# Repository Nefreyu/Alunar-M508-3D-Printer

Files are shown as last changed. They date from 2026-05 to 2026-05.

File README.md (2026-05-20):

# ALUNAR M508 3D Printer — Instructions & Resources (v2.0)

Official instructions, firmware, software and test files for the **ALUNAR M508** (Prusa i3-style) 3D printer. Version 2.0, released September 2016.

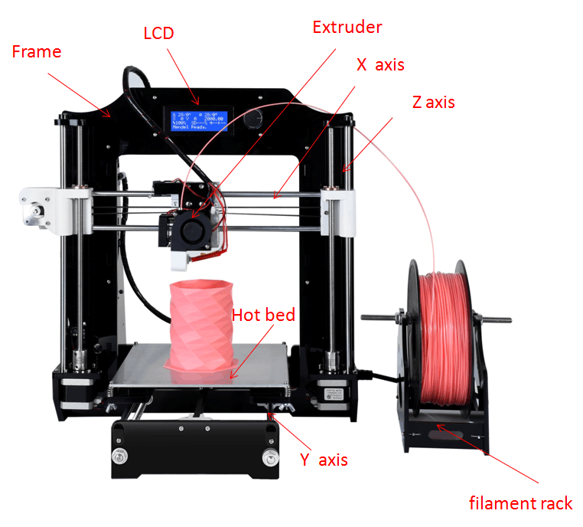
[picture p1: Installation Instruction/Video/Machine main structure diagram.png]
Machine structure


---

## Table of Contents

- [Repository Structure](#repository-structure)
- [Installation Instruction](#installation-instruction)
- [Firmware](#firmware)
- [Software](#software)
- [Test Files](#test-files)
- [Common Problems](#common-problems)
- [Packing List](#packing-list)

---

## Repository Structure

```
├── Installation Instruction/
│   ├── ALUNAR M508 Quick Start Guide_(V2.0).pdf
│   └── Video/
│       ├── 1-Frame assembly.mp4
│       ├── 2-Y-Axis And Hot bed Assembly.mp4
│       ├── 3-Z-X-Axis Assembly.mp4
│       ├── 4-Extruder Assembly.mp4
│       ├── 5-LCD-Assembly.mp4
│       ├── 6-Power And Main board Assembly.mp4
│       ├── 7-Filament Rack Assembly.mp4
│       ├── Open Carton.mp4
│       ├── Power On Inspection.mp4
│       ├── Hot Bed Leveling.mp4
│       ├── LCD Feature And Printing From SD Card.mp4
│       ├── Change Filament When Printing.mp4
│       ├── Manually Change Filament.mp4
│       ├── Test Print.mp4
│       └── finish picture/
├── Firmware/
│   ├── Main_I3/          ← Marlin firmware source code
│   ├── arduino-1.5.4.rar ← Arduino IDE required to flash
│   └── How to download the firmware.pdf
├── Software/
│   ├── RepetierHost_1_0_6/
│   └── Slicing software/
├── TestFile/
│   ├── STLMode/          ← 3D models (.stl)
│   └── TestMode/         ← Ready-to-print G-code files
├── Common problem/
└── Packing list/
```

---

## Installation Instruction

The [`Installation Instruction/`](Installation%20Instruction/) folder contains the full quick start guide and a complete set of assembly videos.

### Quick Start Guide

[ALUNAR M508 Quick Start Guide (V2.0).pdf](Installation%20Instruction/ALUNAR%20M508%20Quick%20Start%20Guide_%28V2.0%29.pdf)

### Assembly Videos

Follow the videos in order for a complete build:

| Step | Video |
|---|---|
| 1 | [Open Carton](Installation%20Instruction/Video/Open%20Carton.mp4) |
| 2 | [Frame Assembly](Installation%20Instruction/Video/1-Frame%20assembly.mp4) |
| 3 | [Y-Axis & Hot Bed Assembly](Installation%20Instruction/Video/2-Y-Axis%20And%20Hot%20bed%20Assembly.mp4) |
| 4 | [Z & X Axis Assembly](Installation%20Instruction/Video/3-Z-X-Axis%20Assembly.mp4) |
| 5 | [Extruder Assembly](Installation%20Instruction/Video/4-Extruder%20Assembly.mp4) |
| 6 | [LCD Assembly](Installation%20Instruction/Video/5-LCD-Assembly.mp4) |
| 7 | [Power & Main Board Assembly](Installation%20Instruction/Video/6-Power%20And%20Main%20board%20Assembly.mp4) |
| 8 | [Filament Rack Assembly](Installation%20Instruction/Video/7-Filament%20Rack%20Assembly.mp4) |

### Operation Videos

| Topic | Video |
|---|---|
| Power On Inspection | [Power On Inspection.mp4](Installation%20Instruction/Video/Power%20On%20Inspection.mp4) |
| Hot Bed Leveling | [Hot Bed Leveling.mp4](Installation%20Instruction/Video/Hot%20Bed%20Leveling.mp4) |
| LCD Features & SD Card Printing | [LCD Feature And Printing From SD Card.mp4](Installation%20Instruction/Video/LCD%20Feature%20And%20Printing%20From%20SD%20Card.mp4) |
| Change Filament While Printing | [Change Filament When Printing.mp4](Installation%20Instruction/Video/Change%20Filament%20When%20Printing.mp4) |
| Manual Filament Change | [Manually Change Filament.mp4](Installation%20Instruction/Video/Manually%20Change%20Filament.mp4) |
| Test Print | [Test Print.mp4](Installation%20Instruction/Video/Test%20Print.mp4) |

> **Note:** Large video files are stored with Git LFS. Make sure you have `git-lfs` installed before cloning: `sudo apt-get install git-lfs && git lfs install`.

---

## Firmware

The [`Firmware/`](Firmware/) folder contains the Marlin-based firmware source for the M508.

- **Source code:** [`Firmware/Main_I3/`](Firmware/Main_I3/) — Arduino sketch (`.ino`) and all associated `.cpp`/`.h` files.
- **Arduino IDE:** [`Firmware/arduino-1.5.4.rar`](Firmware/arduino-1.5.4.rar) — Required version to compile and flash.
- **Flashing guide:** [`Firmware/How to download the firmware.pdf`](Firmware/How%20to%20download%20the%20firmware.pdf)

### Key firmware files

| File | Description |
|---|---|
| `Main_I3/Main_I3.ino` | Main sketch entry point |
| `Main_I3/Configuration.h` | Primary machine configuration (steps/mm, temperatures, etc.) |
| `Main_I3/Configuration_adv.h` | Advanced configuration options |
| `Main_I3/Marlin_main.cpp` | Core Marlin logic |
| `Main_I3/temperature.cpp/h` | Temperature control (hotend & bed) |
| `Main_I3/stepper.cpp/h` | Stepper motor driver |
| `Main_I3/planner.cpp/h` | Motion planning |
| `Main_I3/motion_control.cpp/h` | Arc/straight-line motion |
| `Main_I3/ultralcd.cpp/h` | LCD menu system |
| `Main_I3/cardreader.cpp/h` | SD card support |

### Flashing the firmware

1. Extract `arduino-1.5.4.rar` and install Arduino IDE 1.5.4.
2. Open `Firmware/Main_I3/Main_I3.ino`.
3. Select board: **Arduino Mega 2560**.
4. Connect the printer via USB and upload.

Refer to [`How to download the firmware.pdf`](Firmware/How%20to%20download%20the%20firmware.pdf) for detailed steps with screenshots.

---

## Software

The [`Software/`](Software/) folder contains the tools needed to control the printer and prepare print files.

### Repetier-Host v1.0.6

[`Software/RepetierHost_1_0_6/`](Software/RepetierHost_1_0_6/) — Host software for sending G-code to the printer over USB.

Download from: http://www.repetier.com/

**Setup:**
1. Install the USB serial driver before connecting the printer.
2. Open Repetier-Host and set the correct COM port and baud rate (see [`Baud rate setting.jpg`](Software/RepetierHost_1_0_6/Baud%20rate%20setting.jpg)).
3. Adjust print range settings as shown in [`Print range settings.jpg`](Software/RepetierHost_1_0_6/Print%20range%20settings.jpg).

### Slicing Software — Cura 15.04

[`Software/Slicing software/`](Software/Slicing%20software/) — Converts `.stl` models into `.gcode` files ready to print.

- **Guide:** [`How to use Cura 15.04.pdf`](Software/Slicing%20software/How%20to%20use%20Cura%2015.04.pdf)
- **M508 PLA profile:** [`M508－PLA.ini`](Software/Slicing%20software/M508%EF%BC%8DPLA.ini) — Import this profile in Cura for optimised M508 PLA settings.

---

## Test Files

The [`TestFile/`](TestFile/) folder contains sample models and pre-sliced G-code files to verify the printer is working correctly.

### Ready-to-print G-code (`TestFile/TestMode/`)

| File | Preview |
|---|---|
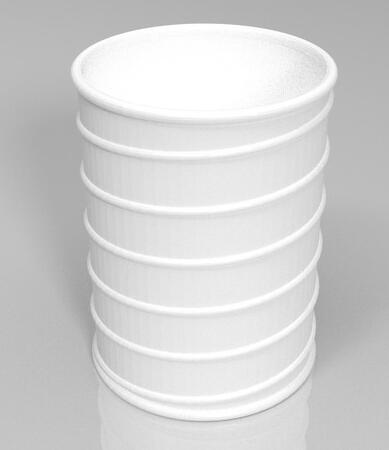
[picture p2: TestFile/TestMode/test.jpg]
test
| `test.gcode` |  |
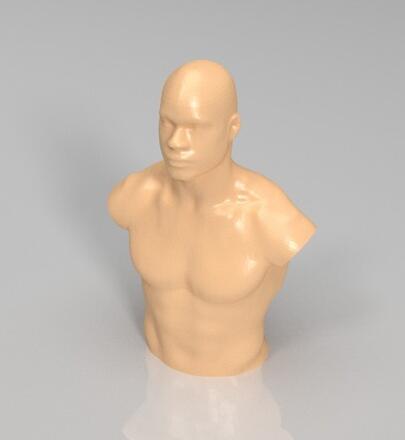
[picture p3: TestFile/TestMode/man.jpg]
man
| `man.gcode` |  |
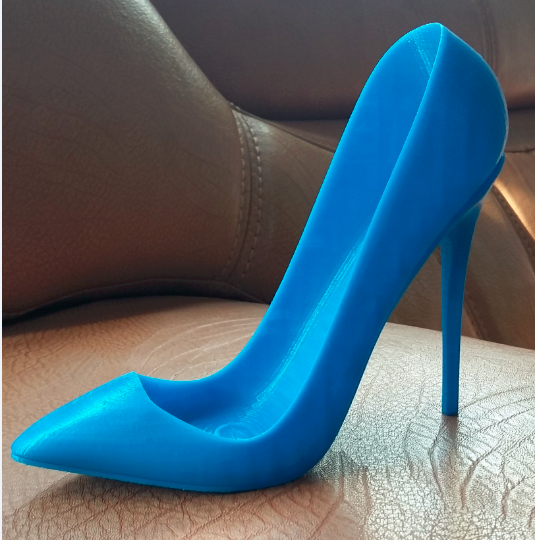
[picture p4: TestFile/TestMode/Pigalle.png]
Pigalle
| `Pigalle.gcode` |  |
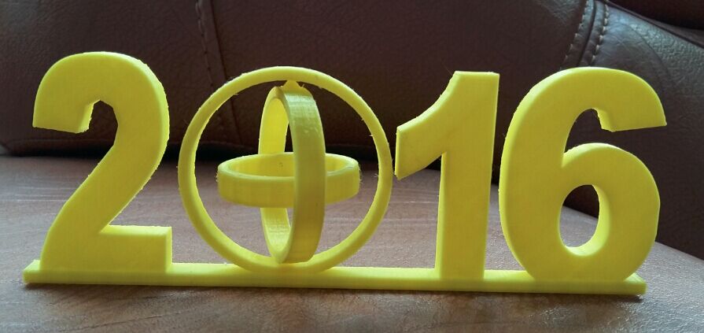
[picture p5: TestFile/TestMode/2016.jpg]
| `2016.gcode` |  |
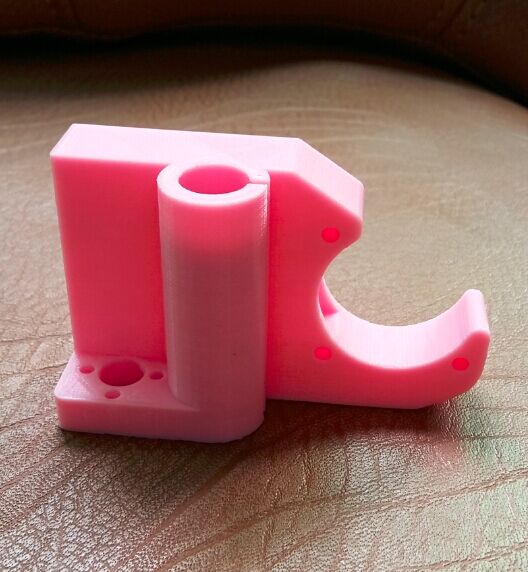
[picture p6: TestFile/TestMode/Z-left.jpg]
Z-left
| `Z-left.gcode` |  |
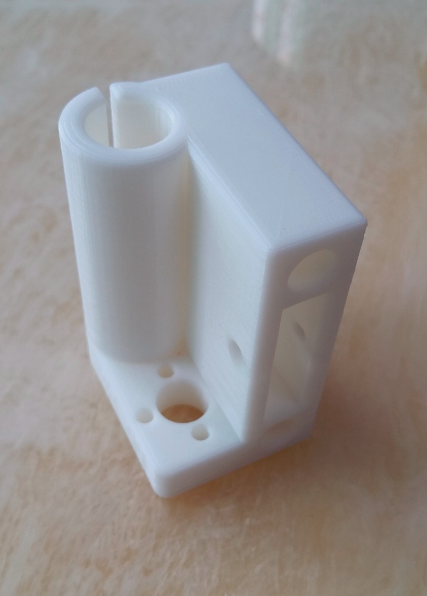
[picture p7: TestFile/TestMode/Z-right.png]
Z-right
| `Z-right.gcode` |  |
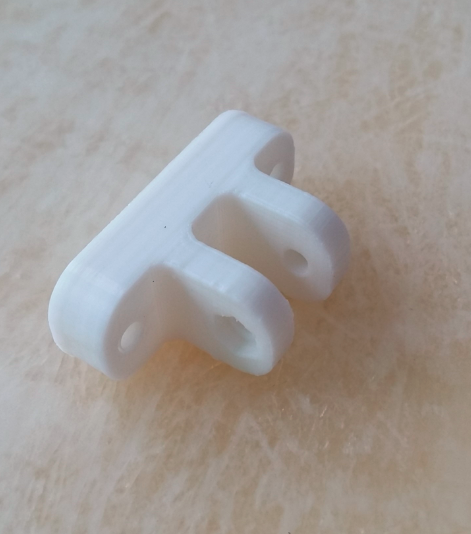
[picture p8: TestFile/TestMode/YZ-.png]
YZ
| `YZ.gcode` |  |
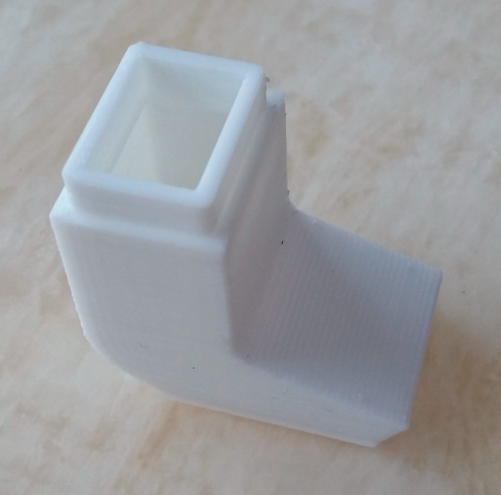
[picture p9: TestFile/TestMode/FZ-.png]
FZ
| `FZ-.gcode` |  |
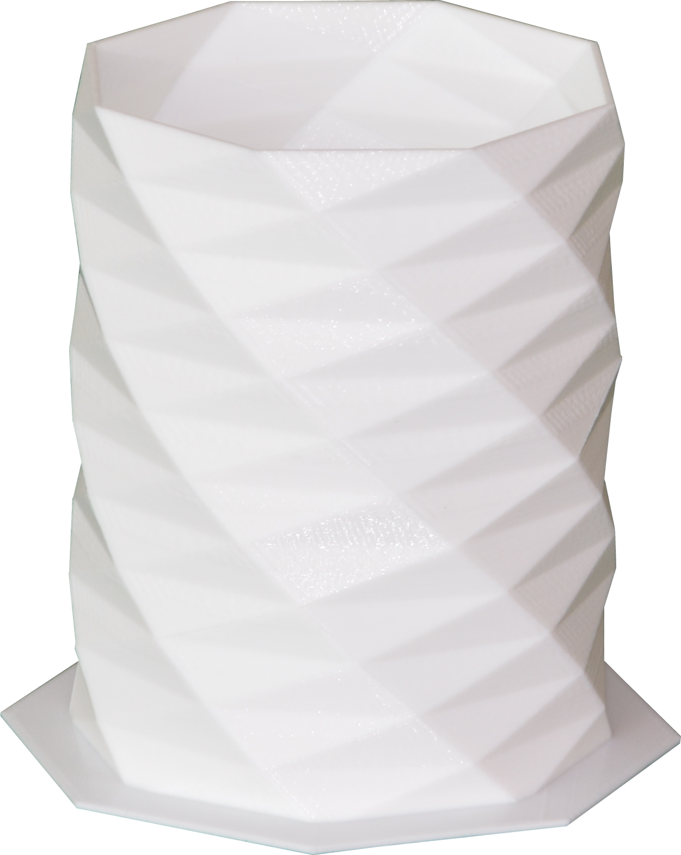
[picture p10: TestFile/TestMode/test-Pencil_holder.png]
Pencil holder
| `test-Pencil_holder.gcode` |  |

### 3D Models (`TestFile/STLMode/`)

| File |
|------|
| `2016.stl` |
| `Pencil_holder.stl` |
| `Pigalle.stl` |
| `FZ-.STL` |
| `YZ.STL` |
| `Z-left.STL` |
| `Z-right.STL` |

---

## Common Problems

The [`Common problem/`](Common%20problem/) folder contains troubleshooting guides:

| Guide | Description |
|---|---|
| [`"Err MINTEMP" Trouble.pdf`](<Common%20problem/%E2%80%9CErr%20%20MINTEMP%20%E2%80%9DTrouble.pdf>) | How to resolve the MINTEMP thermistor error |
| [`LCD Common problem.pdf`](Common%20problem/LCD%20Common%20problem.pdf) | Common LCD display issues and fixes |
| [`Print Quality Troubleshooting Guide.pdf`](Common%20problem/Print%20Quality%20Troubleshooting%20Guide.pdf) | Diagnosing and fixing print quality problems |

---

## Packing List

The [`Packing list/`](Packing%20list/) folder contains the full list of parts included in the M508 kit.

- [`M508 Packing list.pdf`](Packing%20list/M508%20Packing%20list.pdf)
- [`Packing list-M508.pdf`](Packing%20list/Packing%20list-M508.pdf)
- [`Open the carton.jpg`](Packing%20list/Open%20the%20carton.jpg)

---

## Cloning this repository

This repository uses **Git LFS** for large binary files (videos, G-code, STL, RAR). Install Git LFS before cloning:

```bash
sudo apt-get install git-lfs
git lfs install
git clone https://github.com/Nefreyu/Alunar-M508-3D-Printer.git
```

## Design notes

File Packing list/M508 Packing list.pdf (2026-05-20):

No. | Item name No. | Item name Item name | Picture Picture Picture | qty
1 | Frame A | A | 1
2 | Frame B | B | 1
3 | frame unit C | C | 1
4 | frame unit D | D | 1
5 | frame unit H | H | 1
6 | M8 screw rod A length:400mm | | 2
7 | ￠8 Guide rod A length:380mm | 2
8 | linear motion ball slide units | 3
9 | Y axis motor assemble | 1 set
10 | Y bearing support assemble | 1 set

Frame

# Packing list

M3 | PM3*18 | M8

## Y Axis

11 | frame unit P | P | 1
12 | End stop length 1000mm | | 1
13 | frame unit Q | Q | 1
14 | frame unit R | R | 4
15 | frame unit S | S | 2
16 | frame unit L | L | 1
17 | frame unit G | G | 1
18 | Hot bed(with Thermistor) | 1 set
19 | frame unit J | 2

Hot bed

## Z Axis

4-M3*20 | 12-M4*12 | 4-M3*12 | PM3*18 | 2-KA2*12 | M3
4-Spring | 4-M3*30 | 4-M3 | 4-Wing nut M3

J

20 | frame unit K | K | 2
21 | frame unit R | R | 2
22 | frame unit M | M | 2
23 | frame unit N | N | 2
24 | End stop length 400mm | | 1
25 | Z axis motor assemble | | 2 set
26 | ￠8 Guide rod B(length:330mm) | | 2
27 | T8 Threaded rod and nut | | 2 set
28 | Right plastic seat assemble | | 1 set
29 | left plastic seat assemble | | 1set
30 | X axis motor assemble | | 1 set
3-M3*20 | 8-M3*12 | 2-KA2*12 | PM3*18 | M3

## X Axis

31 | ￠8 Guide rod A length:380mm | | 2
32 | U bracket | | 1 set
33 | linear motion ball slide units | | 3
34 | frame unit O | O | 1
35 | End stop length 800mm | | 1
36 | Cooling | 1
37 | Cooling fan | 1
38 | Turbo fan | 1
39 | Fan extender | 1
40 | Extruder motor assemble | 1 set
41 | Nozzle assemble（with thermistor and Cartridge） | 1 set
4-TM4*8 | 2-M4*16 | 2-KA2*12

Extruder

42 | Spare Thermistor | 1
43 | frame unit I | I | 1
44 | Distance washer | | 8
45 | 2004LCD unit | | 1
46 | Knob | | 1
47 | Main control board | 1
48 | Power supply | 1
49 | AC Plug | 1
50 | Power Switch | 1

## LCD

M4*16 | PM3*18
4-PM3*40 | 4-M3 | M3*8

Mainboard、 Mainboard、Power supply Power supply

51 | frame unit E | E | 1
52 | frame unit F | F | 1
53 | Power Supply wire1(red ,yellow,black) | | 3
54 | Power Supply wire2（red) | | 1
55 | Power Supply wire 3 | | 1 set
56 | Motor cables length:600mm | | 3
57 | Motor cables length:1000mm | | 2
58 | power cable | | 1
59 | Tie tube | | 2M
60 | 2GT belt 6mm | | 1.7M
61 | Tie-wrap | | 10
62 | Distance washer | | 3
63 | R clip | 2

64 | M8 screw rod B length:160mm | | 1
65 | frame unit T | T | 2
66 | frame unit U | U | 2
67 | Hexagon screw M3*8 | 6
68 | Hexagon screw M3*12 | 15
69 | Round head screw PM3*18 | 57
70 | Hexagon screw M3*20 | 16
71 | Screw M3*30 | 4
72 | Hexagon screw M3*30 | 4

Filament rack

4-M8 | 4-PM3*18 | M3
3-M3*8 | 3-M3*12 | M3 | PM3*18

Screw,Nut

73 | Round head screw PM3*40 | 6
74 | Screw TM4*8 | 9
75 | Hexagon screw M4*12 | 15
76 | Hexagon screwM4*16 | 5
77 | Screw KA2*12 | 6
78 | Hexago nut M8 | 16
79 | Hexago nut M3 | 67
80 | Wing nut M3 | 6
81 | Washer 8*18*1.5 | 16
82 | Card Reader | 1
83 | Crepe Paper | 1
84 | USB2.0 data cable | 1
85 | SD memory card | 1

Attached parts

86 | Filament | 1
87 | Hexago screw driver 1.5# | 1
88 | Hexago screw driver 2# | 1
89 | Hexago screw driver 2.5# | 1
90 | Hexago screw driver 3# | 1
91 | phillips screw driver 3# | 1
92 | Straight screwdriver 3# | 1
93 | Straight screwdriver 2# | 1
94 | Wrench | 3
95 | Scissor | 1

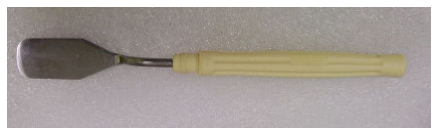
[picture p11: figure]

96 | Trowel | 1
97 | Synchronous belt tension clamp | 2

Tool

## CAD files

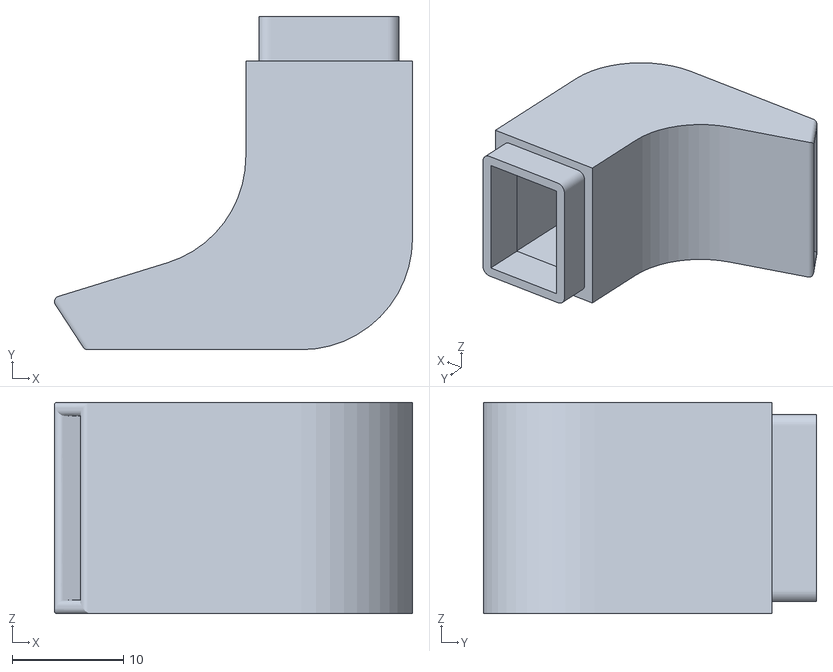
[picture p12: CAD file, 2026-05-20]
TestFile/STLMode/FZ-.STL
32.2 x 30.0 x 19.0

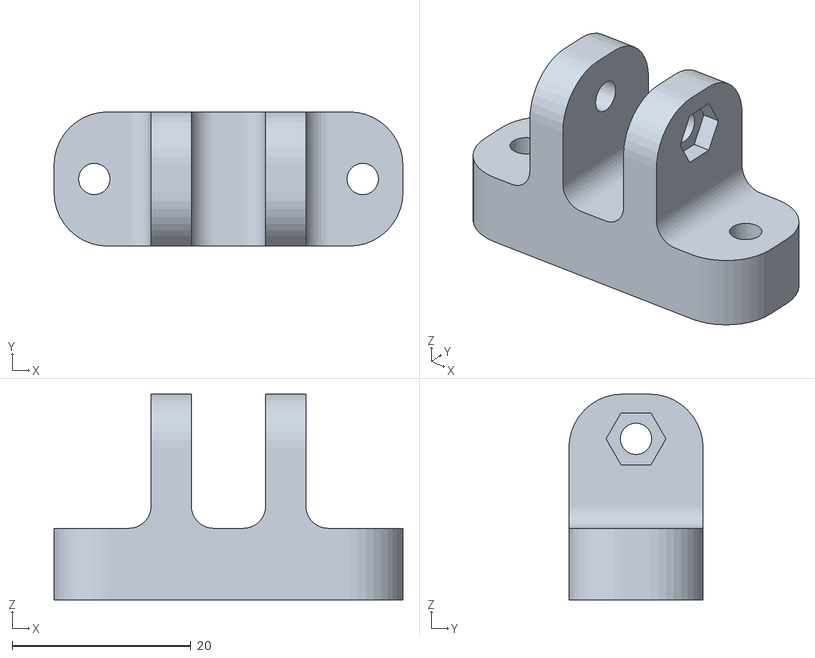
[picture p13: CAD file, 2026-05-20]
TestFile/STLMode/YZ.STL
39.0 x 15.0 x 23.0

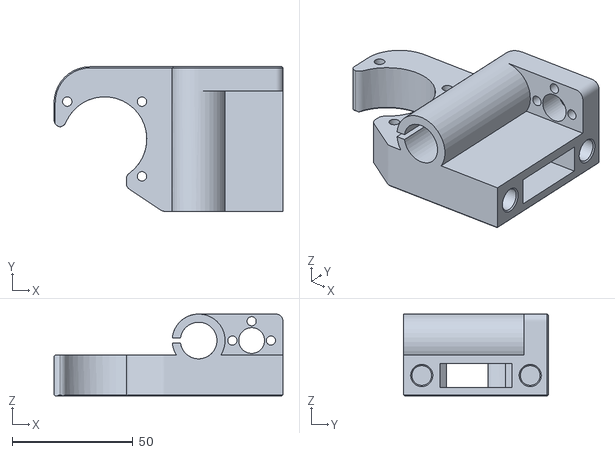
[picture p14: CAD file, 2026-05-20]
TestFile/STLMode/Z-left.STL
95.0 x 60.0 x 34.0

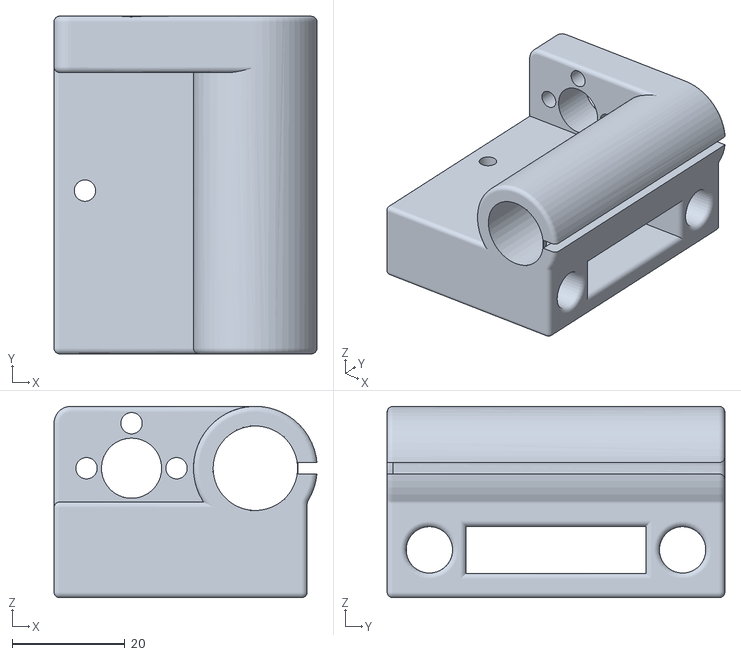
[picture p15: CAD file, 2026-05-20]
TestFile/STLMode/Z-right.STL
46.7 x 60.0 x 34.0

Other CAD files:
TestFile/STLMode/2016.stl
TestFile/STLMode/Pigalle.stl
TestFile/STLMode/Pencil_holder.stl

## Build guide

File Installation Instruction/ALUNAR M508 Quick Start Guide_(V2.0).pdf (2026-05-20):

# ALUNAR 3D Printer M508 Quick Start Guide

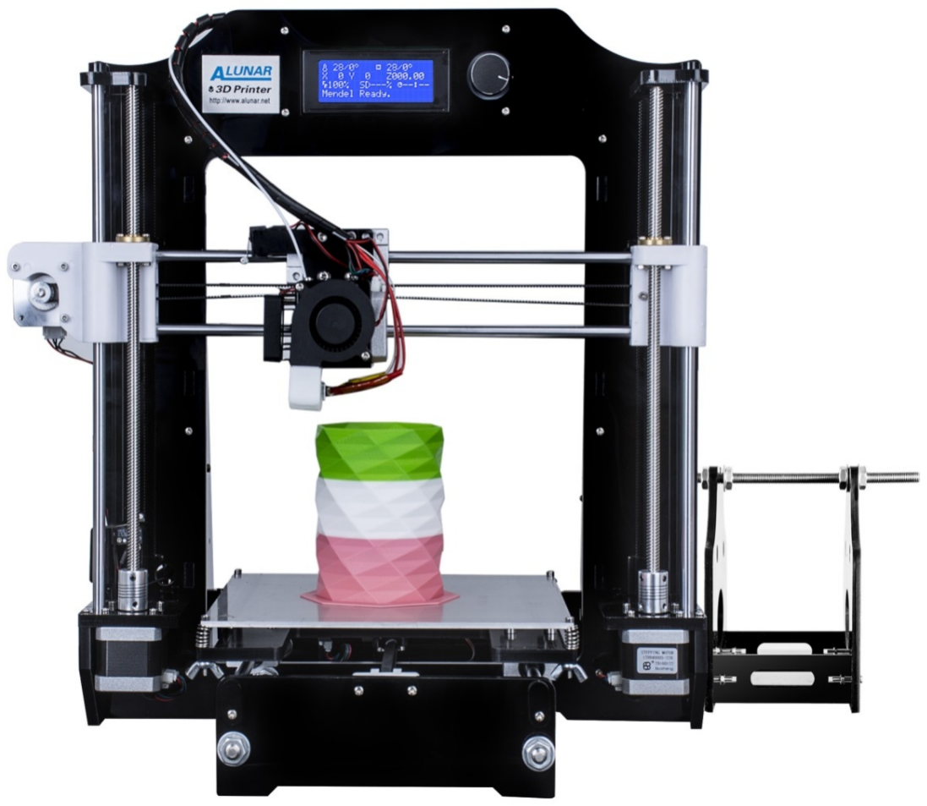
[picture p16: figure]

Service Skype:alunar3d@hotmail.com Service Email:service@alunar.net

# Catalogue

## Foreword

Thanks in advance for choosing our M508 3D Printer! With the Quick Start Guide (hereinafter as “Guide”), you could enjoy accomplishing the assembly, Test and Printing step by step. Meanwhile, you will also learn the structure principle and its special FDM printing technology deeply, and then you will get great progress on not only the theoretical knowledge but also the manipulative ability.
To give play to the bigger effect of the printer and ensure the worry-free buying, smooth and enjoyable using, we spare no effect to consider the problem and difficulty you will meet with from when you order the printer and make detail videos and pictures to show the exact settle way. We write this “Guide” elaborately in great detail and we will always accompany with your using 3D printer. The kits would come to you with high-class parts and need you to put them together. So please read the “Guide” carefully before you assembly and use the printer .Please use the printer in strict accordance with the “Guide” to avoid any defective or invalid use caused by improper operation. So please keep the “Guide” for your easy reference.

Special Tips:

With our objective of constant update for our printer, we would not make future notice to you if some specifications and models updated. And we apologize for the inconvenience would lead to you.
We will do our best to help and solve the problem with our products. Your positive review and feedback are so appreciated!
Wish you a nice day!

## 1. Machine parameters

Printing technology | FDM | Nozzle diameter | 0.3(default),0.4,0.5mm
Print size | 200*200*180mm | Printing precision | 0.1-0.3mm
Filament | PLA /ABS /HIPS/WOOD | Printing speed | 40-100mm/s (proposal)
Filament diameter | ￠1.75mm | Working condition | 10-40℃
Number of extruder | 1 | Humidity | 20-50％

## 2. Flow Diagram for Quick Use Manual

## 3. Important Notice and Attentions

3.1 Keep the assembling operation platform level.
3.2 Please ensure that you move to the right tap position for input voltage (110V or 220V) of the power supply (as shown in the picture).
Calibration | Printing Test | Senior Instruction | Frequently Asked Questions and Settle Way

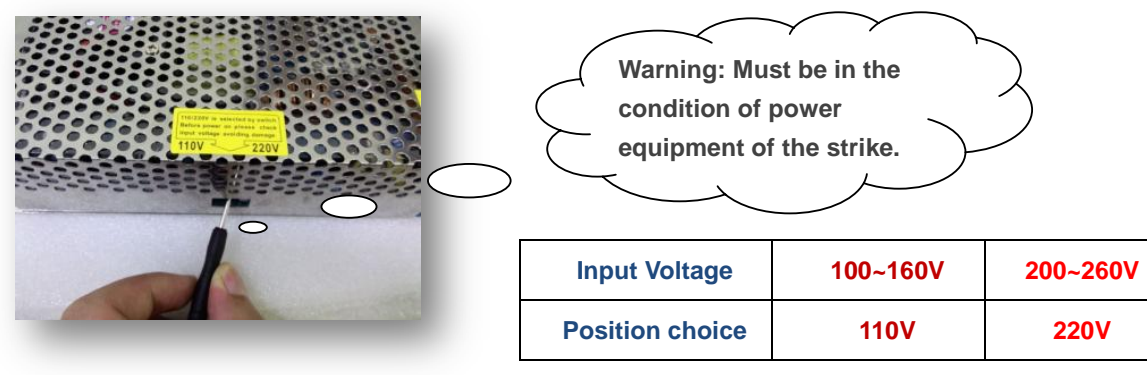
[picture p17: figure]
Input Voltage; Position choice; Warning: Must be in the condition of power equipment of the strike.

3.3 You need to make a proper degree of tightness of the pull belt for X axis& Y axis. 3.4 Ensure manual operation slide smoothly when you install the X, Y, Z axis.
3.5 When equipped the hotbed, you should keep the 4 angle level for sure.
3.6 Ensure the correct wiring for controller board and plug tightly into the exact socket.
3.7 Don’t plug and unplug the wiring for controller board when power on, especially don’t plug and unplug the connect wiring for power supply.
3.8 Don’t touch the extruder and hotbed when printer is power on to avoid the scald.
3.9 Before installation please remove the protective paper.

3.10 Before printing please paste on crepe paper.

## 4. Preparatory Work

1. Tool and kit preparing: one level desk at more than 2 sq. m. size, one computer, one scissor, SD card reader, power supply and so on.
2. Open the box you got, and read the “Guide“ from the SD card. We suggest that you should copy all the documents to the computer from the SD card and then start assembling according to the “Guide” (SD-Card: \Installation Instruction\ALUNAR 3D Printer M508 Quick Start Guide)

## 5. Preinstallation Checklist

### 5.1 Step Way of Opening Box

Please look over the whole box appearance and make sure whether the box is damaged (if damaged, please feel free to contact with our customer service); and then please open the box and check the kits list as per “opening the carton” (SD-Card: \Packing list\Open the carton.)And “Video of opening carton” (SD-Card: \Installation Instruction\Video\ Open Carton.MP4)

### 5.2 Take an account of kits

Please check out all the parts and make sure if any part is lost or damaged as per the “Packing List” (SD-Card: \Packing list) and video “Open carton” (SD-Card: \Installation Instruction\Video\Open Carton.mp4.) Please feel free to contact our customer service once you find out that you lost or got any defective parts (except leading by the inartificial reason). We will try our best to settle your problems as soon as possible）.

## 6. Assembly and Calibration for M508

M508 assembly: Please assembly the printer by following the step1- step7 on assembly diagram and video, and pay attention the prompt for key of assembling.(SD-Card: \Installation Instruction\Video)

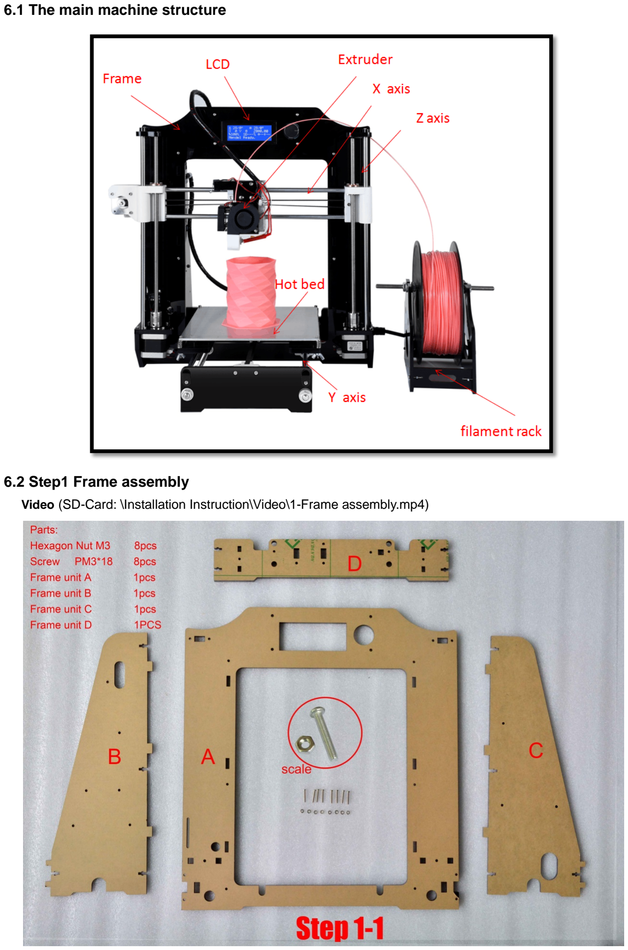
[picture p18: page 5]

### 6.1 The main machine structure

### 6.2 Step1 Frame assembly

Video (SD-Card: \Installation Instruction\Video\1-Frame assembly.mp4)

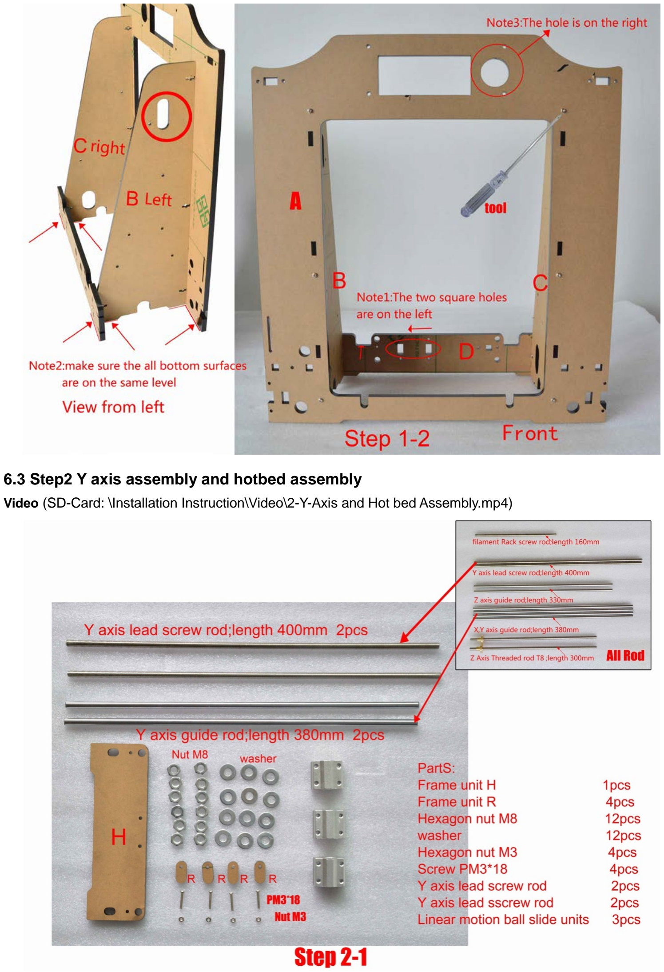
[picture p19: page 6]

### 6.3 Step2 Y axis assembly and hotbed assembly

Video (SD-Card: \Installation Instruction\Video\2-Y-Axis and Hot bed Assembly.mp4)

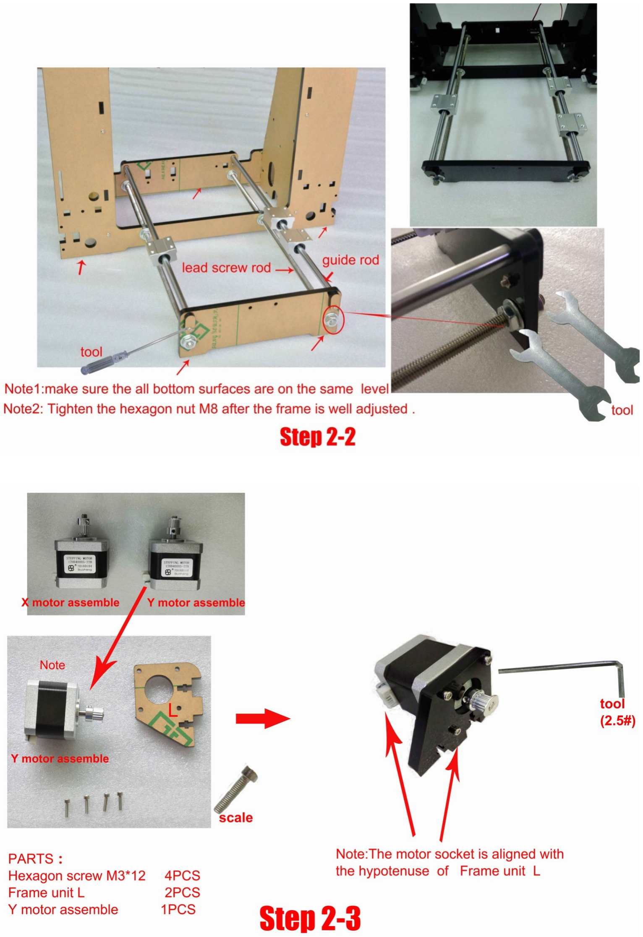
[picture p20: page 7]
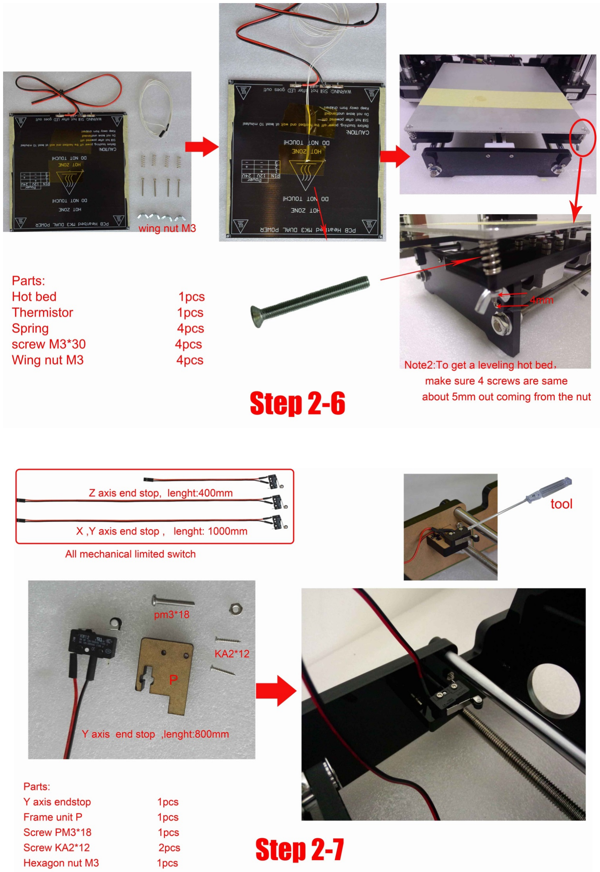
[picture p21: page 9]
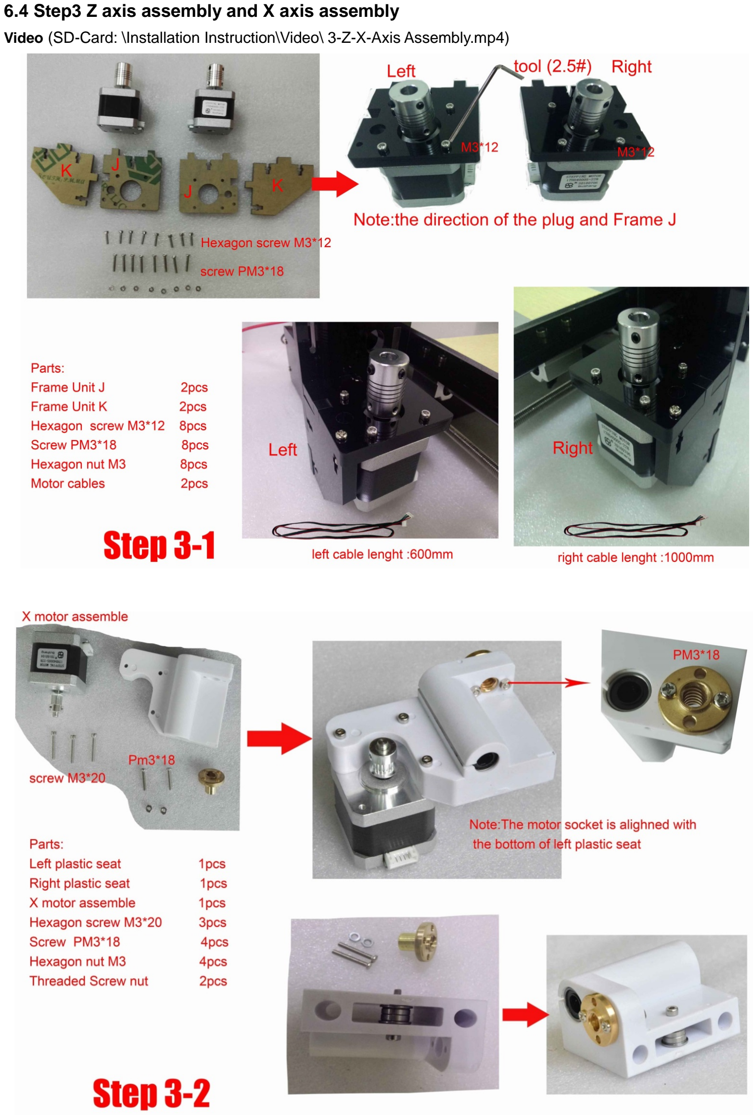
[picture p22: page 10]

### 6.4 Step3 Z axis assembly and X axis assembly

Video (SD-Card: \Installation Instruction\Video\ 3-Z-X-Axis Assembly.mp4)

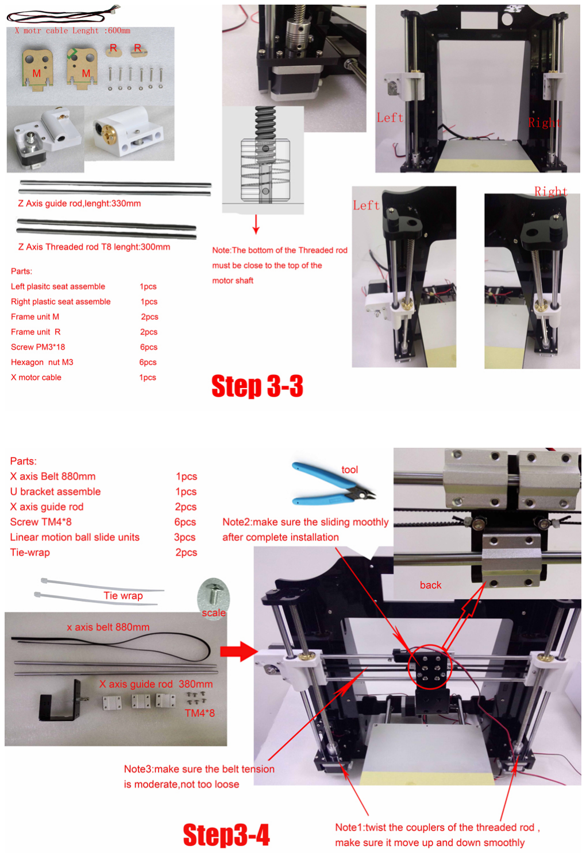
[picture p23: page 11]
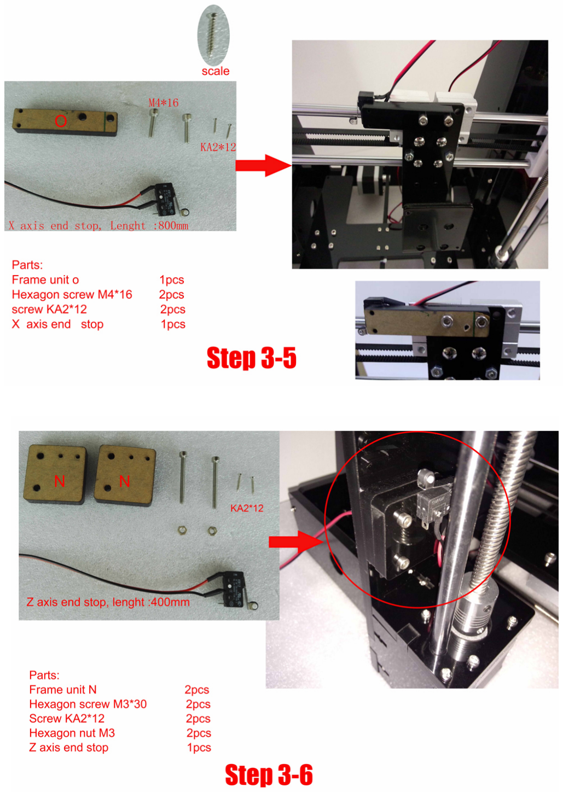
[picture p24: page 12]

### 6.5 Step4 Extruder assembly

Video (SD-Card: \Installation Instruction\Video\ 4-Extruder Assembly.mp4)

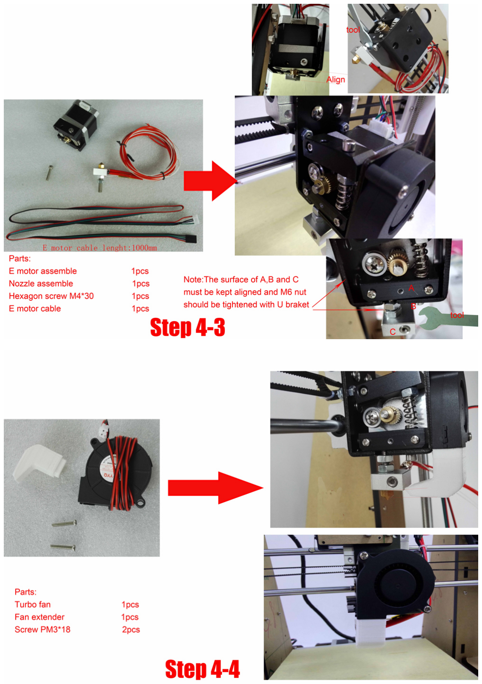
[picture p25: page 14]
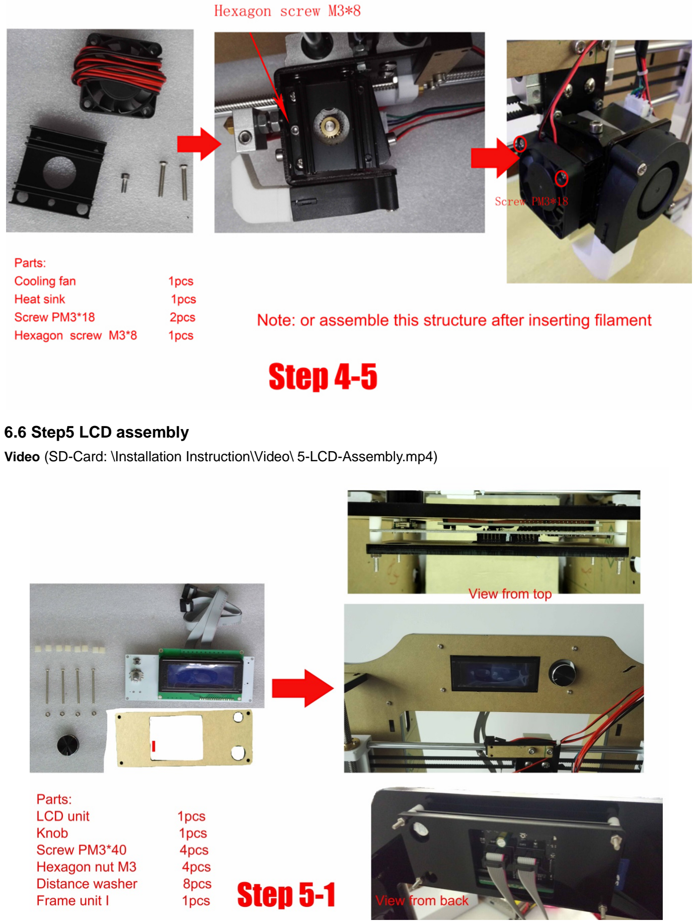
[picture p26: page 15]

### 6.6 Step5 LCD assembly

Video (SD-Card: \Installation Instruction\Video\ 5-LCD-Assembly.mp4)

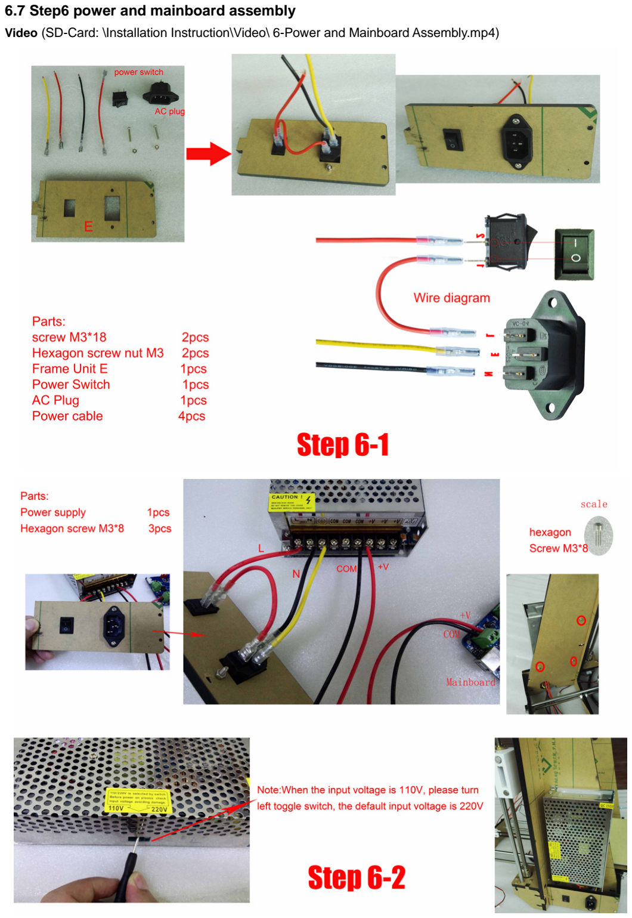
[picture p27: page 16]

### 6.7 Step6 power and mainboard assembly

Video (SD-Card: \Installation Instruction\Video\ 6-Power and Mainboard Assembly.mp4)

### 6.8 Step7 Filament rack assembly

Video (SD-Card: \Installation Instruction\Video\ 7-Filament Rack Assembly.mp4)

## 7. Testing and Commissioning

### 7.1 Power on test

When connecting the power supply to your printer, please make sure whether the power indicator light is on, LCD screen show correctly or not, hotbed and the extruder can be heated rightly or not, the thermistor, turbine fan and radiator fan works normally or not; (SD-Card:\ Installation Instruction\ Video\ Power On Inspection.mp4)

### 7.1.1 Turn on the power switch, LCD display, as shown in Figure

### 7.1.2 Fan check

### 7.1.3 Nozzle and hot bed heating inspection

“Prepare” →“Preheat PLA”

### 7.1.4 Back to the origin inspection

“Prepare” →“Auto Home”

X axis will move towards left, Y axis will move towards back, Z axis will move down, each axis will stop moving till their limit switch

Switch on the power, this fan works

OK | NG | NG

OK

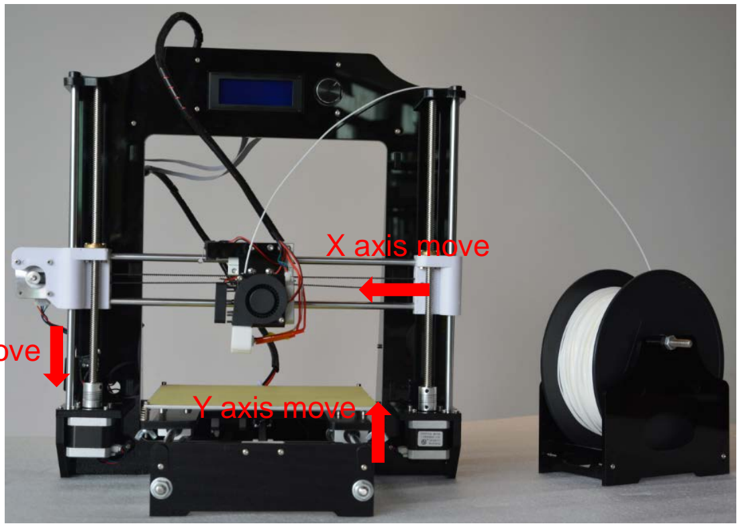
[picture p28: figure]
X axis move; Y axis move

### 7.2 Hotbed leveling test:

Hotbed leveling test: Please make calibration to level the hotbed according to the video(SD-Card:\Installation Instruction\Video\Hot Bed Leveling.mp4)After assembling, you need to level the bed when firstly print

### 7.2.1 Rough Debugging to level hotbed

7.2.1.1 Adjust the screws at the 4 angle of the hotbed to make the screws 4mm out of the nut (Picture 7.1)； 7.2.1.2 Move the nozzle as near as possible to the hotbed, and pull the extruder with hand to the upper everywhere of hotbed to check if the distance between the nozzle and 4 angle of hotbed is accordant(Picture7.2);
7.2.1.3 Hold the T coupling at left& right bottom of Z axis with hand and rotate it to make the nozzle to 4mm above the hotbed (Picture7. 3, 7.4)
7.2.1.4 Move the Z axis limit switch to the proper position, to make that the Z axis stop once the bottom of left Z axis nut support meet the sphere of limit switch (Picture 7.5)

# Z axis move

Picture 7.1 | Picture 7.2 | Picture 7.3

4mm

### 7.2.2 Accurate Debugging

7.2.2.1 Auto home and make the XYZ axis back to origin (Picture 7.6)；
7.2.2.2 Screw the screws at 4 angle of hotbed to make the nozzle above 1mm to the hotbed (Picture 7.7)

(PS: After Auto home, please click “Disable Steppers” or turn off the power, otherwise, you will can’t move the XYZ axis by hand)

### 7.2.3 Fine Debugging when printing

Please check the printing status of first layer when you first printing by your printer. If you need, you can screw the screws at 4 angle of hotbed to the best position (as shown on picture 7.10)
The different printing effect depends on the different distance between nozzle and hotbed：

### 7.3 Change the Filament

Watch the video “Manually Change Filament “and get the operation way of this special feature of this printer (SD-Card: \Installation Instruction\Video\ Manually Change Filament.MP4)

### 7.3.1 Change the Filament when not printing

Pull out the filament: Firstly preheat the nozzle to the exact temperature(PLA：200～220℃，ABS：240～260℃) Once the temperature is up to the same as setting, press the upper aluminum piece on the extruder motor with left hand, meanwhile push down to extrude part of filament and then pull out it rapidly with right hand.(PS:Don't pause in the process to avoid the jam lead by the cooling midway. Picture 7.11, 7.12)
(SD-Card: \Installation Instruction\Video\ Change Filament When Printing.MP4)

Insert the Filament：Press the upper aluminum piece on the extruder motor and meanwhile insert the filament into the throat (You can cut the filament into oblique angle with scissor to plug in smoothly. Picture 7.13), push down to extrude part of filament (Picture7.12), then let the aluminum piece go, finally clear up the filament extruded.

Picture 7.4 | Picture 7.5

Picture 7.6

Picture 7.7

Picture 7.8 | Picture 7.9 | Picture 7.10
The distance between nozzle and hotbed is too high | | The distance between nozzle and hotbed is proper

The nozzle is too close to hotbed

### 7.3.2 Change the Filament When Printing

7.3.2.1 Click “tune” →“change filament”；The printer stop working and the XY axis would be back to the origin, then the extruder would send back the filament from the printer automatically (Picture 7.14)； 7.3.2.2 Change the filament manually and press the knob, then the printer would go on printing starting from the former position of printing model.

### 7.4 Feature Demonstration

Feature Demonstration: watch the video “LCD Feature and Printing from SD Card” and get the operation way of all basic features; (SD-Card: \Installation Instruction\Video\LCD Feature and Printing From SD Card.MP4)

### 7.4.1 Instruction of Operation part for Off-line Printing

Off-line printing operation for 3D printer constitutes 5 parts as below (as shown above Picture 7.16): Power Switch, Outlet, LCD Screen, Spin Button, and SD Card
And you can control the knob easily and quickly by rotating and pressing.

Picture 7.12

Filament

The Upper
Aluminum
Piece
Picture 7.11 | Picture 7.13
Power Switch | Outlet | LCD Screen | Knob | SD Card

Picture7.16

Picture 7.14

Picture 7.15

### 7.4.2 The first Memo Interface

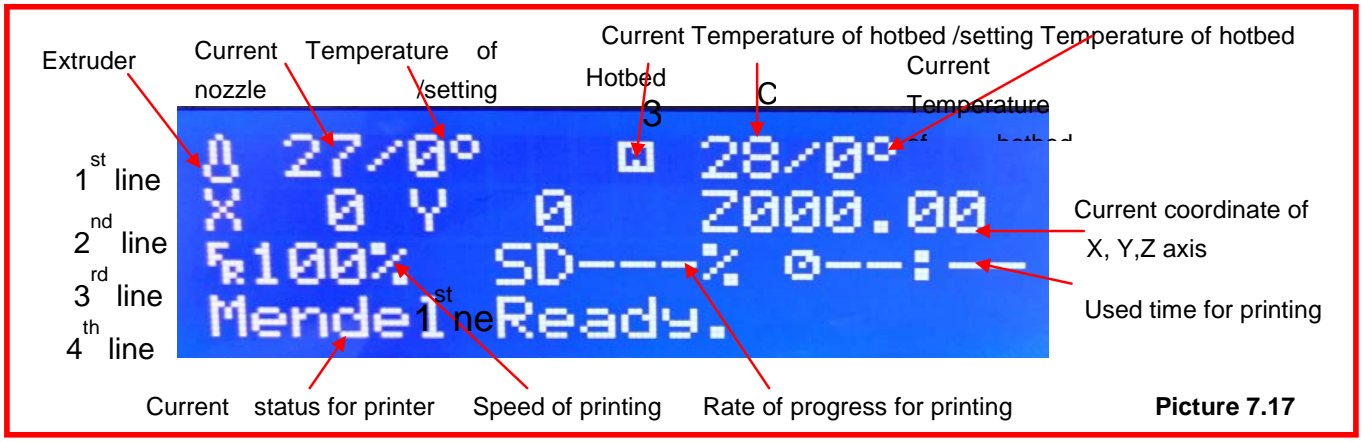
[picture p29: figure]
nozzle; /setting; Temperature of nozzle; Extruder; Hotbed; Current coordinate of X, Y,Z axis; Speed of printing; Rate of progress for printing; Used time for printing; Current Temperature; hotbed; Current status for printer; line; Picture 7.17

Plug the outlet and switch on, then access to the first memo interface (as shown on picture 7.17) which consist of the 4 parts as below:
temperature, XYZ coordinate system, Printing status, Current situation of system
1. 1st line
It will show the temperature of nuzzle and hotbed, the two parts separated by “/” will show respectively before
and after the current and setting temperature, Such as | , it shows that setting
temperature for nuzzle is180°and the current is 72°, it shows that setting temperature for hotbed is 70°and the current is 31°
2. 2nd line
It will show the exact position of XYZ axis move onto in the printing.
3. 3rd line
It will show the speed and rate of progress of printing, and used time for printing. And it shows the multiple speed of printing which is set up in the slicing.“100%” means the exact speed and 200% means that printing by the speed 2 times as the one setting in slicing
4. 4

th
line
It shows the current status of printer, such as

### 7.4.3 The secondary memo interface

Press the knob and access to the 2nd memo interface, and it will show differently as below when the printer is working or not

7.4.3.1 The 2nd memo interface when not printing (as shown on picture 7.18)

Click the (Info screen) and back the 1st page of memo interface
Click the (Prepare) and access to set up for printing prepare such as preheat the nozzle& hotbed, auto home, move the nozzle and hotbed
Click the (Control) and set up for the temperature of nozzle& hotbed, parameter of stepper motor, restoring the fail-safe, and storage memory etc.
Click the (Print from SD) and choose the printing file from the SD card, and it is sort of by copy time.

Current Temperature of hotbed /setting Temperature of hotbed Current Temperature of

Picture7.18

Information
Prepare for printing
Parameter Adjustment
Print from SD

7.4.3.2 The 2nd memo interface when printing (as shown on picture 7.19)

Click the (Info screen) and back the 1st page of memo interface
Click the (Tune) and adjust the temperature of nozzle& hotbed, speed of fan when printing
Click the (Control) and set up for the temperature of nozzle& hotbed, parameter of stepper motor, restoring the fail-safe, and storage memory etc.
Click the (Pause Print) and pause the printing
Rotate down the knob and click the (Stop Print) to stop printing

### 7.4.4 Prepare for printing (prepare)

7.4.4.1 When 3D printer not printing, rotate the knob and click “prepare” in the secondary memo interface (Picture 7.20) and then access to the 3rd memo interface (Picture 7.21)

(1) Unlock the disable stepper motor: click the (Disable Steppers) and then you can manual move the XYZ axis smoothly
(2) Click the (Auto Home) and the XYZ axis will move back to the origin
(3) Click the (Preheat PLA) and then the nozzle would be heating up to the same as the setting temperature for PLA, meanwhile, the LCD will also go back to the first memo interface.
(4) Click the (Preheat ABS) and then the nozzle would be heating up to the same as the setting temperature for ABS, meanwhile, the LCD will also go back to the first memo interface
(5) Click the (Cool down), the temperature for nozzle and hotbed would be cool down to 0°automatically.
(6) Click the (switch power off) to turn off the power (it is not put into use at present)
(7) Click the (Move Axis) to control the move of XYZ, input & output the filament. Please don’t take the 10mm as unit for Z axis movement and input& output the filament (extruder).

### 7.4.5 Move the axis and input& output the filament (Move Axis)

Click the “Move Axis” and do as the guide to all parts, then you will access to the 4th(Picture 7.23), 5th(Picture 7.24), and 6th(Picture 7.25) memo interface step by step. And then you could only take the 1mm & 0.1mm as unit for the Z axis movement and input & output filament (extruder).

Picture 7.19

Information
Current Parameter Adjustment Parameter Adjustment
Pause print
Stop print

Picture 7.21

Picture 7.20

PS: The axis movement is based on current coordinate and it can only move to the positive direction.

The extruder could move to the positive& negative direction to input& output the filament.

### 7.4.6 The Parameter Adjustment when not printing (Control)

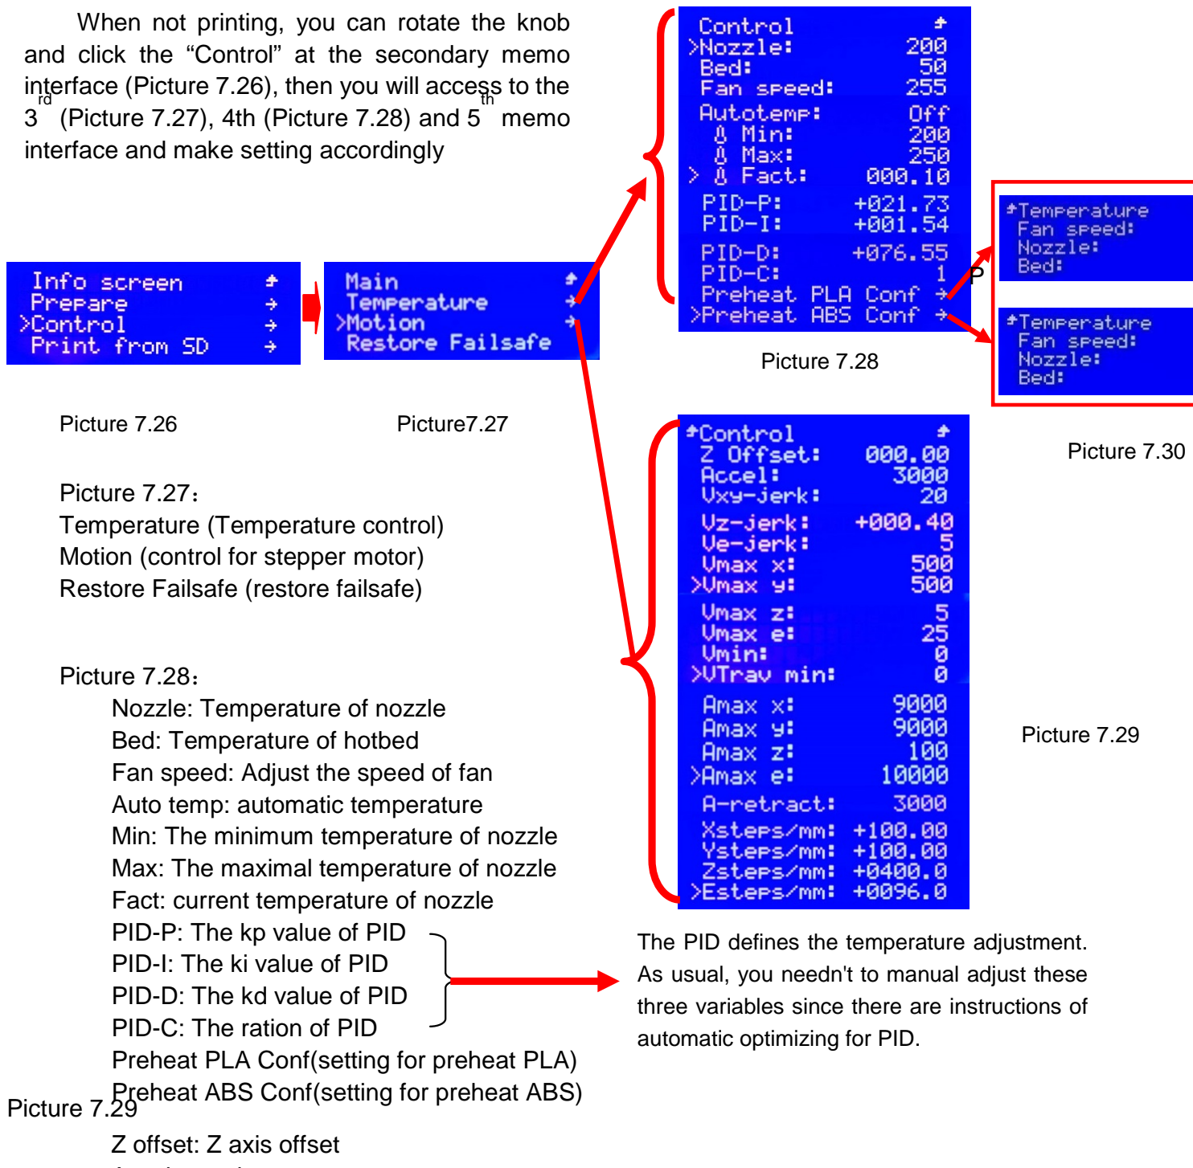
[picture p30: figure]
Picture 7.29 Z offset: Z axis offset; Picture 7.26; Picture7.27; Picture 7.28; Picture 7.29; Picture 7.30; Picture 7.27： Temperature (Temperature control) Motion (control for stepper motor) Restore Failsafe (restore failsafe); memo; interface and make setting accordingly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

Accel: accel
Vxy-jerk: The speed variation of XY axis with no need acceleration Vz-jerk: The speed variation of Z axis with no need acceleration Ve-jerk: The speed variation of Extruder with no need acceleration Vmax X: The maximal speed of X axis

Picture 7.24

Picture 7.22 | Picture 7.23

Picture 7.25

When not printing, you can rotate the knob and click the “Control” at the secondary memo interface (Picture 7.26), then you will access to the (Picture 7.27), 4th (Picture 7.28) and 5

Preheat PLA Conf(setting for preheat PLA) Preheat ABS Conf(setting for preheat ABS)

The PID defines the temperature adjustment. As usual, you needn't to manual adjust these three variables since there are instructions of

Vmax Y: The maximal speed of Y axis Vmax Z: The maximal speed of Z axis
Vmax E: The maximal speed of Extruder
Vmin:
VTrav min: The Maximal speed of quicken enablement Amax X: The maximal acceleration speed of X axis Amax Y: The maximal acceleration speed of Y axis Amax Z: The maximal acceleration speed of Z axis Amax E: The maximal acceleration speed of Extruder A-retract: The acceleration at * mm/s
Xsteps/mm: The distance of each step for X axis motor Ysteps/mm: The distance of each step for Y axis motor Zsteps/mm: The distance of each step for Z axis motor Esteps/mm: The distance of each step for Extruder motor

### 7.4.7 Real-time parameter adjustment (Tune)

Picture 7.30
FAN Speed：Adjust the speed of fan
Nozzle ：When not printing, you can set up the temperature of nozzle according to filament you used. As usual, the temperature for PLA is up to 180-200°and for ABS is 230-250°
Bed：When not printing, you can set up the temperature of hotbed according to filament you used. As usual, the temperature for PLA is up to 50-70°and for ABS is 90°

Picture 7.31

Picture 7.32

7.4.7.1 Only when the 3D printer working, the secondary memo interface would be show as picture 7.31.And click the “Tune” to access to the 3

rd
memo interface (Picture 7.32), and then you can adjust the parameter by rotating knob.

Speed (speed of printing): Adjust the speed of printing by rotating the knob
You can also the speed of printing by rotating the knob directly at the first memo interface
Nozzle (the setting temperature of nozzle): You can adjust the temperature of nozzle when printing, then the nozzle would be heating up to the temperature as you set.
Bed (the setting temperature of hotbed): When printing, you can adjust the temperature of hotbed if you find the setting temperature by slicing is too high or too low. Then the hotbed would be heating up to the temperature as you set.
Fan speed (speed of fan): As usual, it is not necessary to adjust the speed of fan, but you can also set up it by your choice.
Flow (measure of extrusion): The unit for flow is percentage and you can set up it to the proper quantity if you find out it is not enough or too much when printing
Change filament::Click it and the nozzle would be back to origin, then the filament feed roll would roll back to output the filament automatically

### 7.4.8 Parameter adjustment when printing (Control)

### 7.4.9 Print from SD

## 8. Printing Test

After all the above-mentioned test and you make sure the printer works well. Now you can get start a printing test. Please insert the SD Card into the card slot on the left back of the screen and then choose the “test-*.g code” file and start printing with rotating the spin button. (SD-Card: \Installation Instruction\Video\Test Print.mp4)

Congratulations! You’ve already accomplish the whole assembly for the M508. Please feel free to contact our customer service if you have any problem on technology or other. We will spare no effect to settle your problems accordingly. As you complete the printing test, you would be pride of yourself by creating the first 3D printer work. And welcome to share your amazing and successful DIY experience to our page online (www.alunar.net)

When 3D printer printing, the secondary memo interface would be shown as（Picture 18), click the “Control” to access to the 3

rd
(Picture 7.27) 4

th
(Picture 7.28,7.29), ,5

th
(Picture
7.30)memo interface
Picture 7.33 | Picture 7.34

Picture 7.35

Picture 7.36

Pict2ure 7.37

You needn’t to adjust it since all the setting on Picture 7.35， 7.36 & 7.37 is almost the same as the one on Picture 7.28， 7.29 & 7.30

Ve-jerk: The speed variation of Extruder with no need acceleration

Picture 7.38 | Picture 7.39

When 3D printer is not printing, click “print from SD” and access to 3

rd
page of memo interface (Picture
7.39) then start printing by choosing the “.g code” file

## 9. Senior Instruction

### 9.1 Off-line Printing

Off-line Printing: copy the “X.gcode”file to the SD card and insert the card into your printer, then start your printing directly. And you need to change it to “X.gcode”if the file you want to print is “X.STL”.

How to use slicing software: Please open the “SD-Card: \ Software\Slicing software” and click the software“Cura 15.04” to slice the printing file as per the use manual shown on “How to use Cura 15.04”.

### 9.1.1 How to use Cura 15.04

Note:
(1).We advise new user to use Cura for Slicing.
(2).The data you will slice depend on the item you need to print.
(3).Before you start printing, please make sure the parts of printer work well and the distance between nozzle and hotbed is about 0.1mm (A4 Paper thickness).

Ps: Most data was default, you need to change them depends on the object you want to print.

Step1:

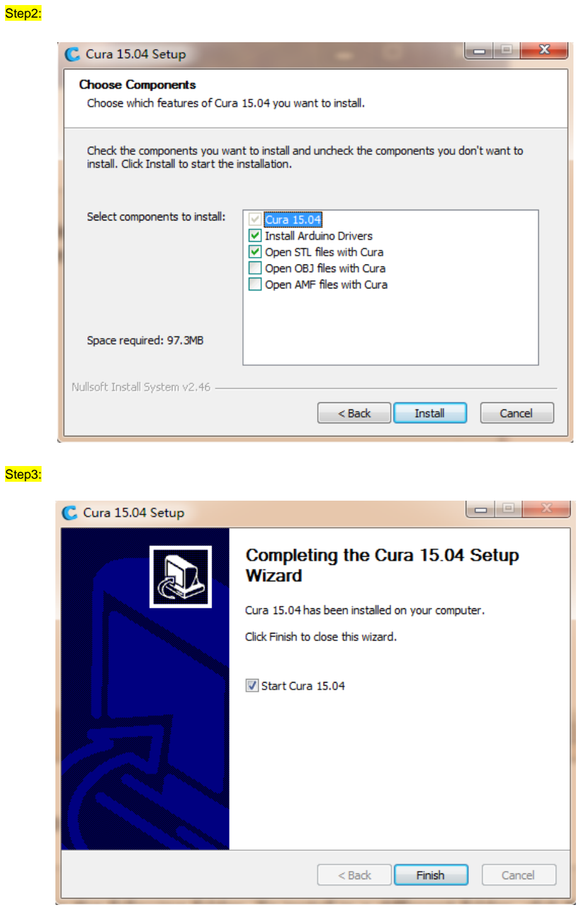
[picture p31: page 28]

Step2:

Step3:

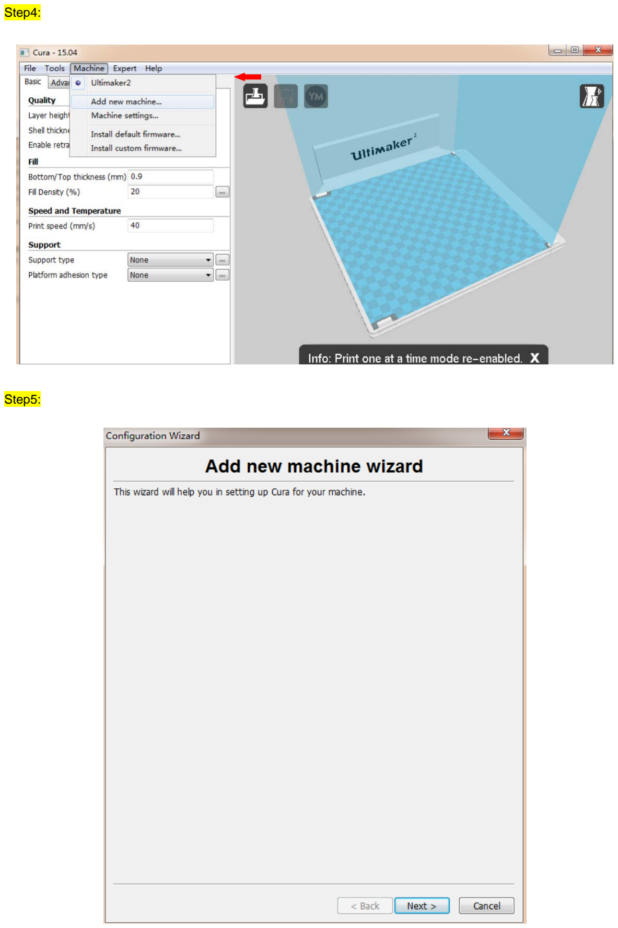
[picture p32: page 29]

Step4:

Step5:

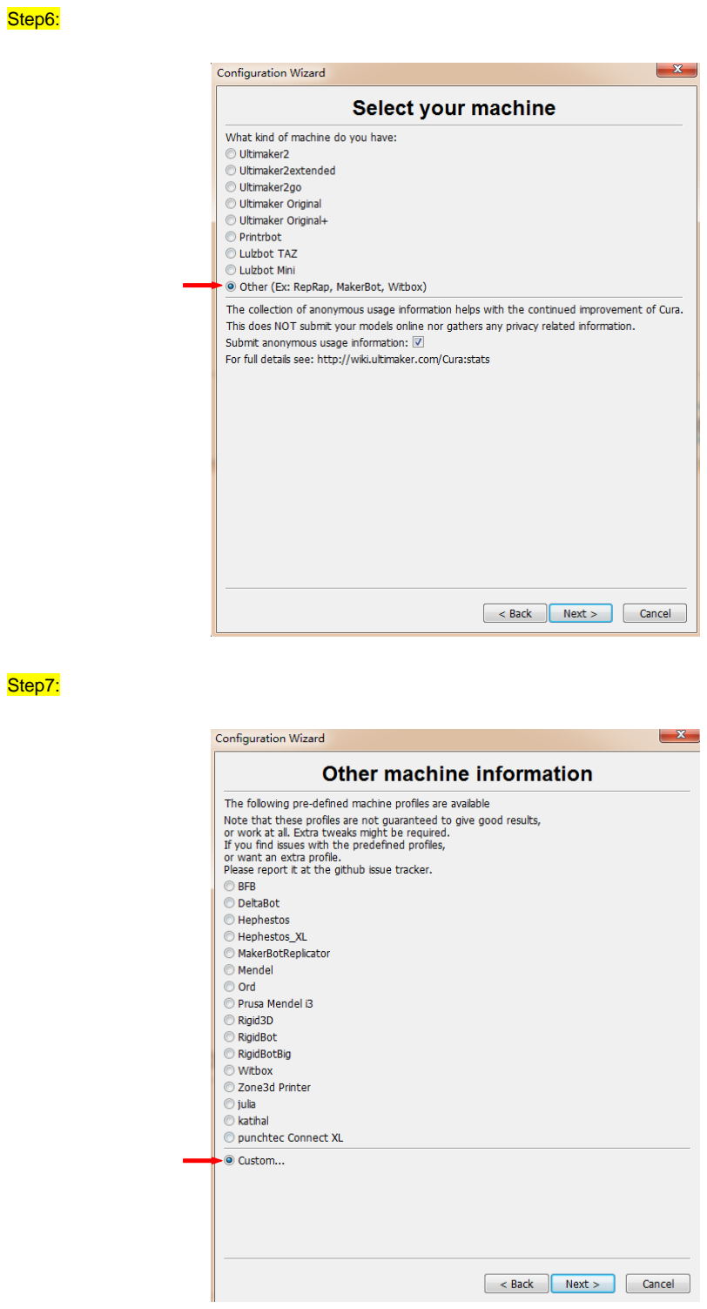
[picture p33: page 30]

Step6:

Step7:

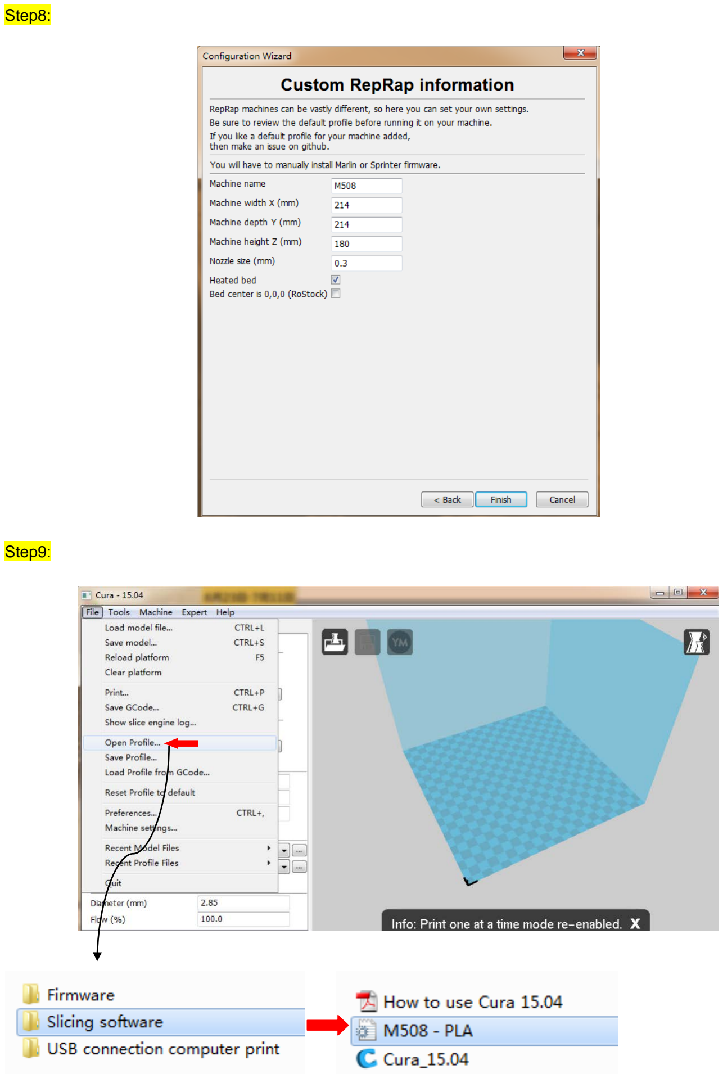
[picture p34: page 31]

Step8:

Step9:

Step10:

Step11:

Open file (STL)

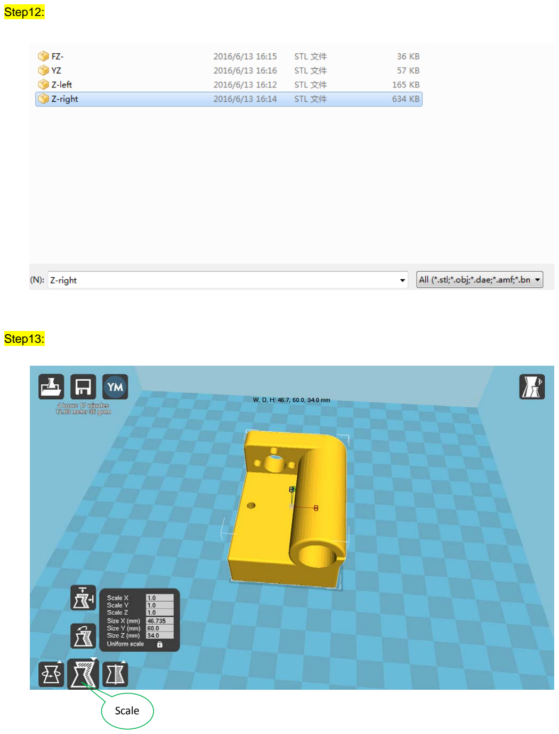
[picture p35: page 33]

Step12:

Step13:

Scale

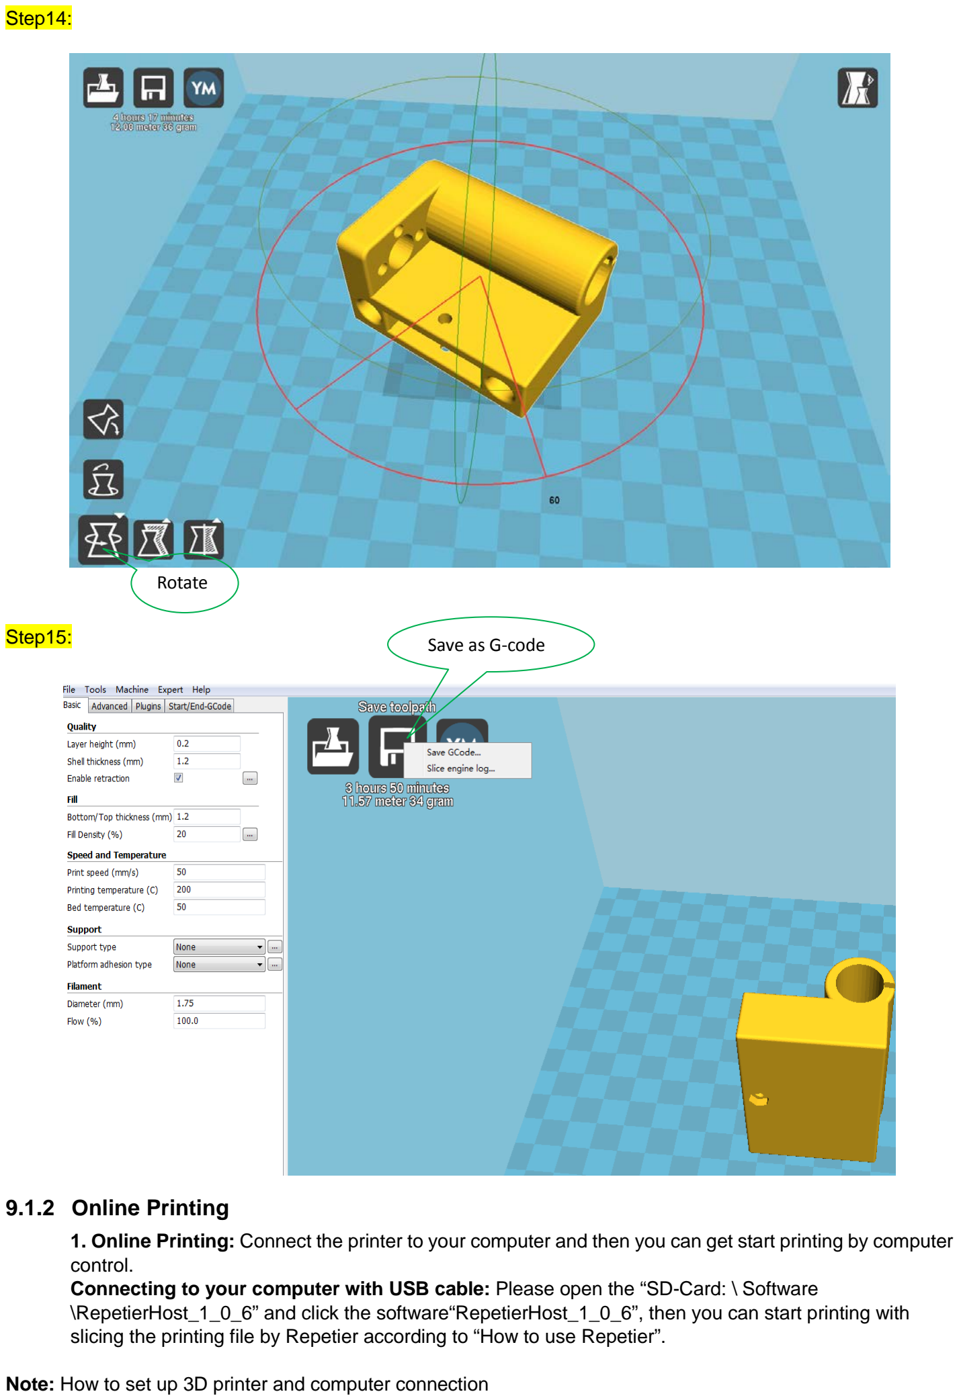
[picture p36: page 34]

Step14:

Step15:

### 9.1.2 Online Printing

1. Online Printing: Connect the printer to your computer and then you can get start printing by computer control.
Connecting to your computer with USB cable: Please open the “SD-Card: \ Software \RepetierHost_1_0_6” and click the software“RepetierHost_1_0_6”, then you can start printing with slicing the printing file by Repetier according to “How to use Repetier”.

Note: How to set up 3D printer and computer connection

Save as G-code

Rotate

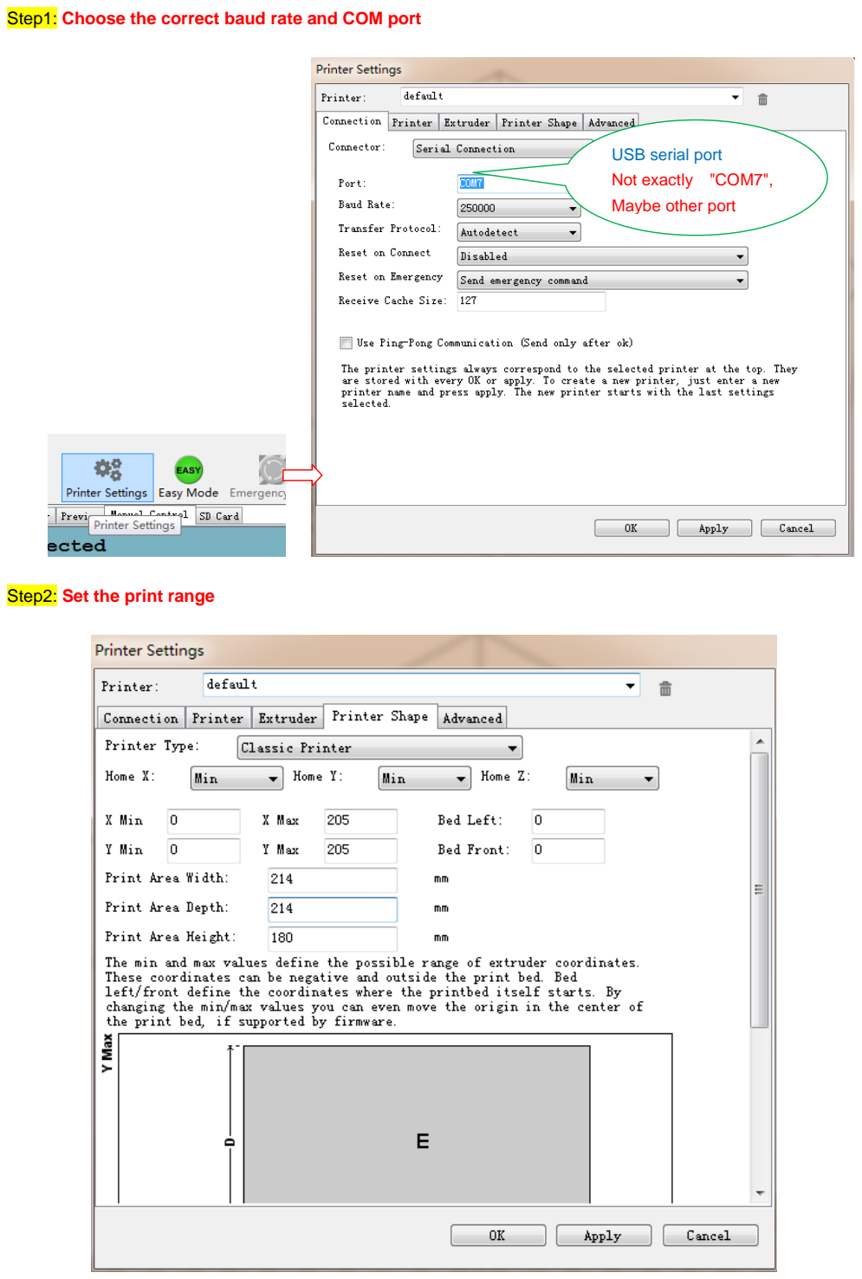
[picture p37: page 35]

Step1: Choose the correct baud rate and COM port

Step2: Set the print range

USB serial port
Not exactly "COM7",
Maybe other port

Step3: Start to connect

Step4: Connecting successfully

## 10. Frequently Asked Questions and Solutions

Please get the “Common problem” from the SD card for your reference (SD-Card: \Common problem)

### 10.1 “Err: MINTEMP” Alarm processing method

# Hot bed

# Nozzle

Motherboard

Press the reset button on the motherboard or after power-off restart, Appear “Ready Mendel”, “Err:
MINTEMP” Alarm release.

(Reset button)

①②(Temperature display) | (Normal temperature display interface)

Reason: the hot bed and the nozzle thermistor are not connected to the main board "TB", "TH";

①②(No temperature display)

① | ②

Normal temperature display interface

①：Nozzle real time temperature ②：Hot bed real time temperature

②(No temperature)display

Reason: the hot bed thermistor is not connected to the main board "TB";

Reason: the nozzle thermistor is not connected to the main board“TH”

①(No temperature) display

### 10.2 Trouble: LCD screen is not bright

### 10.3 Trouble: Rotation button cannot be up and down the selection menu

Solution method：
(1). Confirm whether the power supply is normal ；
(2) Confirm the LCD screen on the EXP1, EXP2 port is connected with the EXP1, EXP2 port on the motherboard, and no loose or poor contact

(LCD screen)

(Motherboard) (Main board power indicator light, power supply is normal)

(Solution method）：

(Confirm that the EXP2 interface is properly connected, and that there is no contact with the bad phenomenon )；

(Normal figure)

(Abnormal figure)

(By rotating the button on the left side of the pointer can be up and down the selection menu)

(No response to the left pointer by the rotation button)

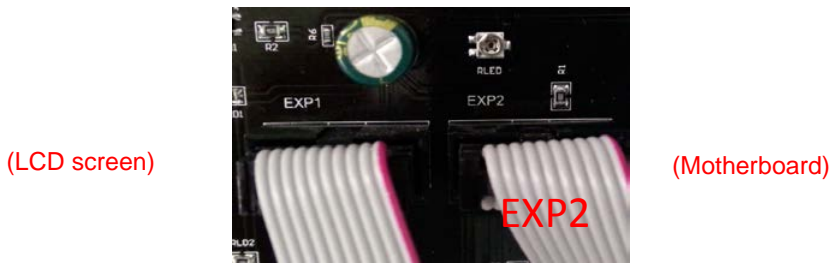
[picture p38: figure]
(LCD screen); (Motherboard); EXP2

### 10.4 No extruded filament when printing

### 10.5 Problems on the distance between nozzle and hotbed

### 10.6 Model Dislocation when printing

Picture 10.1 （Figure 1）
2.The heating temperature is OK,push down the filament and confirm the nozzle extrude the filament (Picture 10.2)；

1.Check and confirm if the heating temperature is up as the setting ( picture 10.1)；

2.1 If the nozzle extrude the filamentby pushing down, please check and confirm if the filament feed wheel is loose or not (Picture 10.3)

Extrusion Wheel

Picture 10.3 (Figure 3)

2.2If nozzle didn’t extrude the filament, the nozzle must be blocked and clean it

The distance between nozzle and hotbed is too high

The nozzle is too close to hotbed
Settle way: adjust the nozzle to the thickness of 1 A4 paper above the hotbed.

The distance between nozzle and hotbed is proper

Picture 10.4

Y Direction

Picture 10.5

Dislocation for X direction

Picture 10.6

Dislocation for Y direction Dislocation for X &Y direction

Picture 10.7

PS: Please visit our site if you would like to get more information on 3D printer: http://www.alunar.net.

Motor drum in-phase of X axis | X axis Belt | Motor drum in-phase of Y axis

Y axis Belt

1. Settle way of Dislocation for X direction: Check if Motor drum in-phase of X axis is loose or if the X axis belt is too tight or loose;
2. Settle way of Dislocation for Y direction: Check if Motor drum in-phase Y axis is loose or if the Y axis belt is too tight or loose.
3. Settle way of Dislocation for X &Y direction: Check if Motor drum in-phase X & Y axis is loose or if the X &Y axis belt is too tight or loose.

## 11. Wire Diagram of Main board

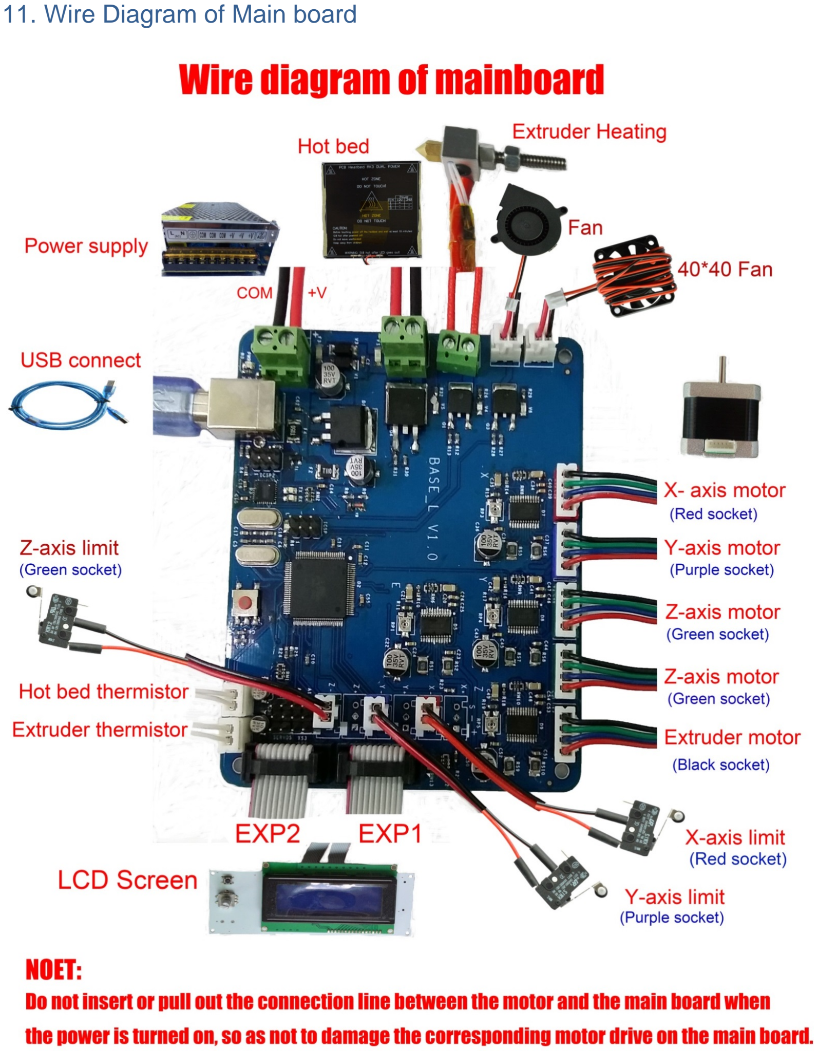
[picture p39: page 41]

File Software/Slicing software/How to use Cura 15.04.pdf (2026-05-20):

How to use Cura 15.04

Note:

1、We advise new user to use Cura for Slicing.

2、The datas you will slice depend on the item you need

to print.

3、 Before you start printing, please make sure the parts

of printer work well and the distance between nozzle

and hotbed is about 0.1mm(A4 Paper thickness).

Ps: Most datas was default, you need to change them

depends on the object you want to print.

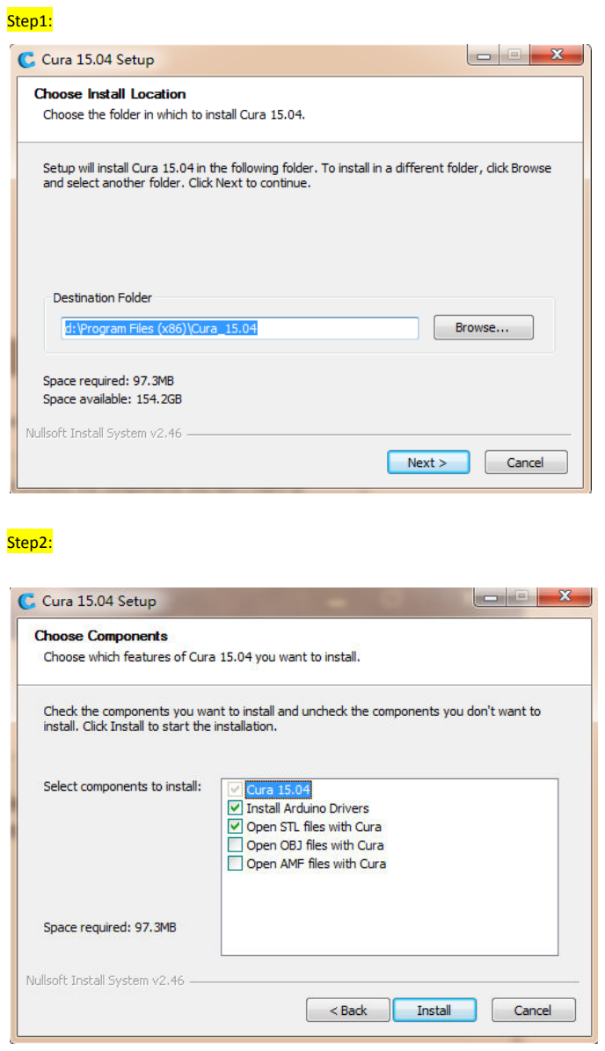
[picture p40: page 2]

Step1:

Step2:

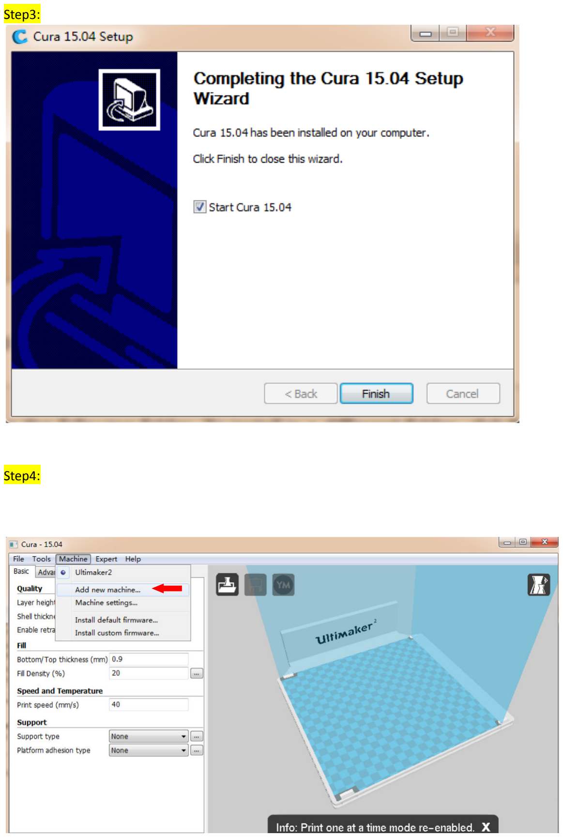
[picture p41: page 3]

Step3:

Step4:

Step5:

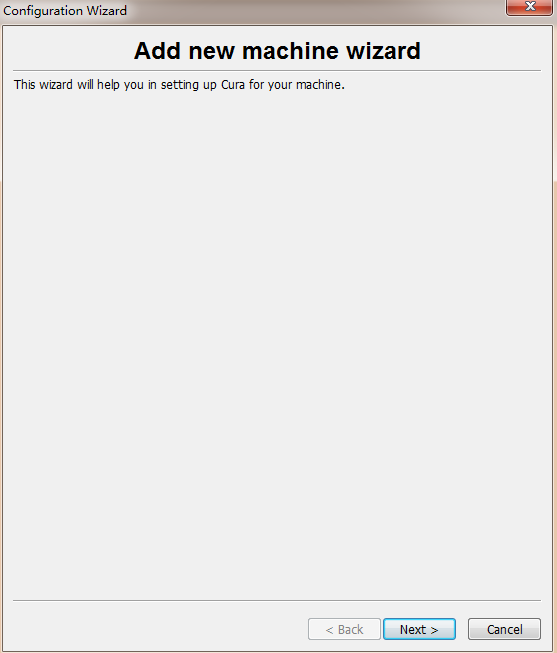
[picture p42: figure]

Step6:

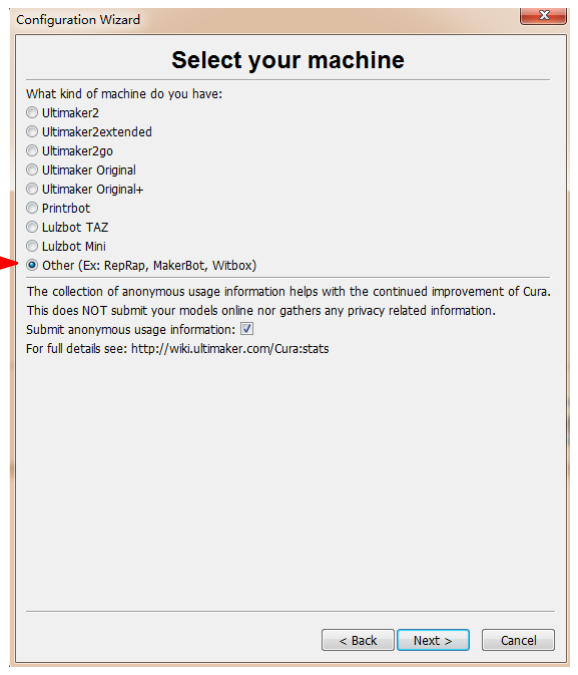
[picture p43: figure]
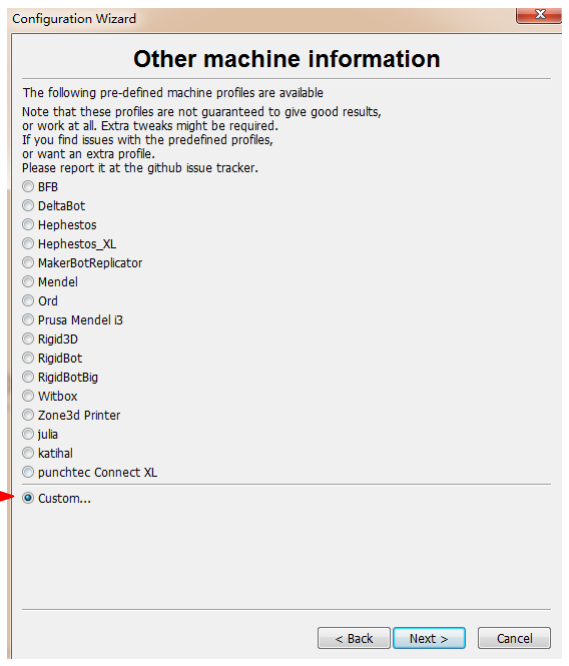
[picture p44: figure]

Step7:

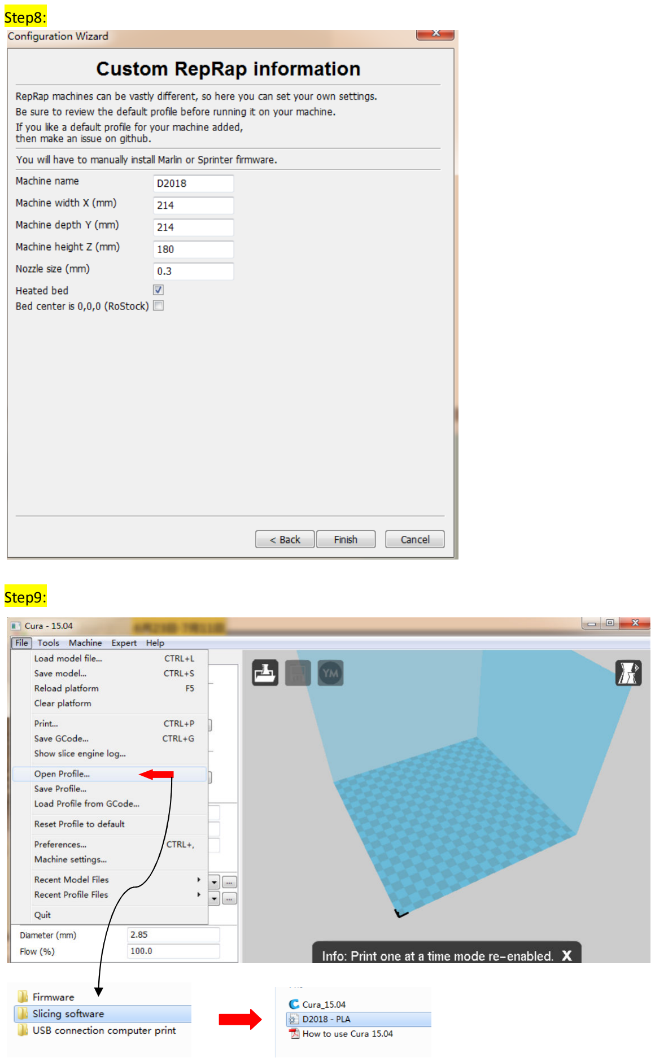
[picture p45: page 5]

Step8:

Step9:

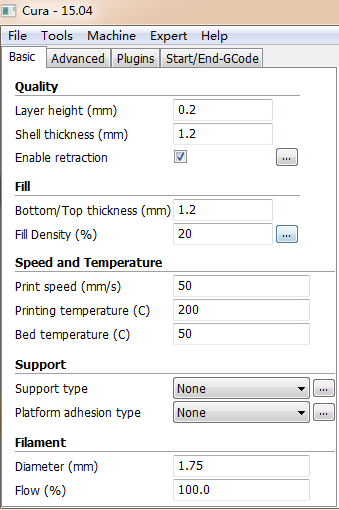
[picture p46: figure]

Step10:

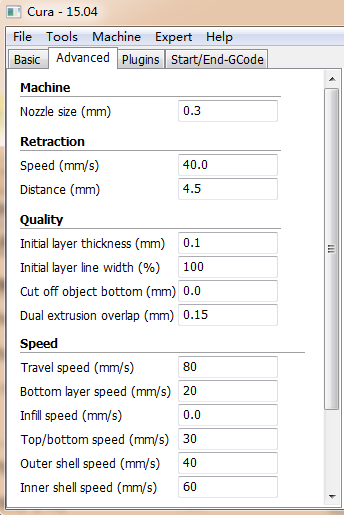
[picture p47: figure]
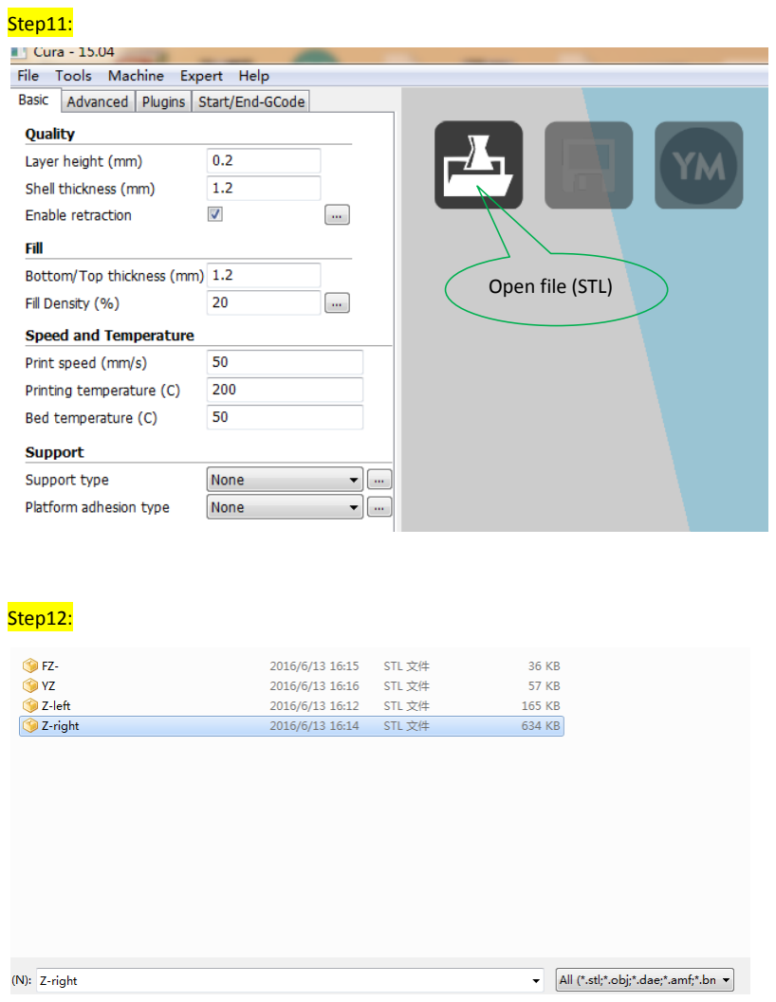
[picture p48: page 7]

Step11:

Step12:

Open file (STL)

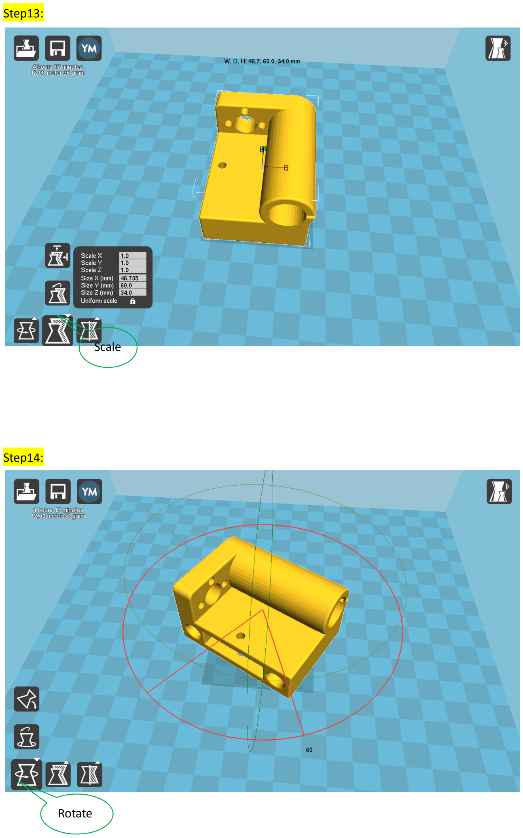
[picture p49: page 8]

Step13:

Step14:

Scale

Rotate

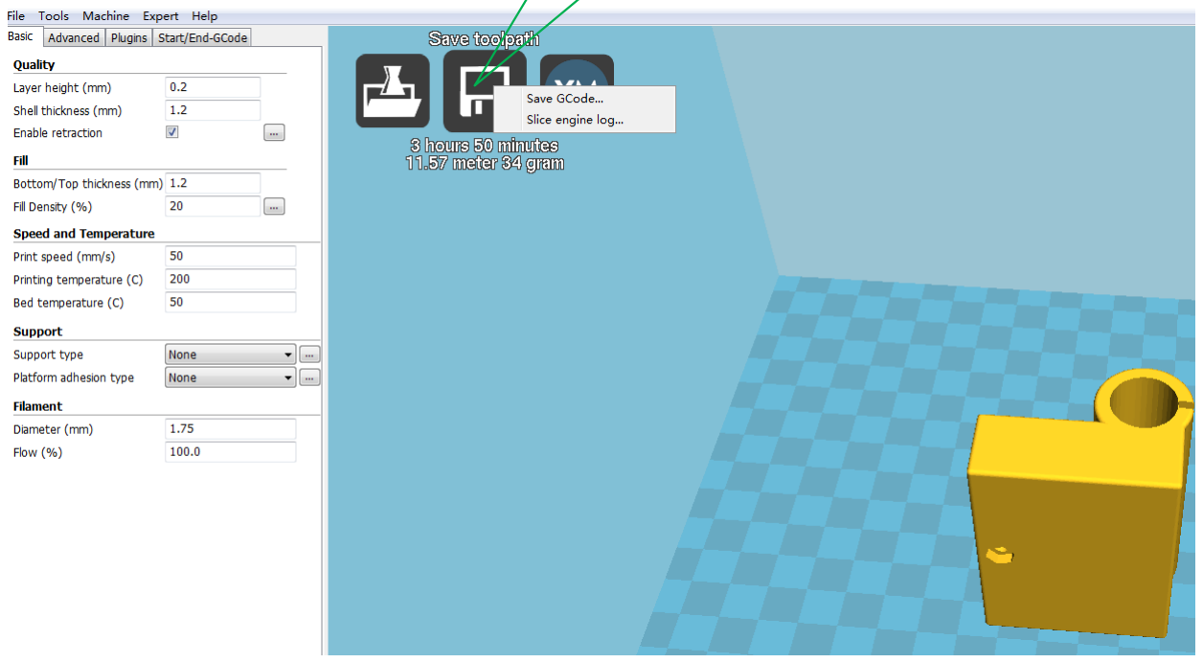
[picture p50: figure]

Step15:

Save as G-code

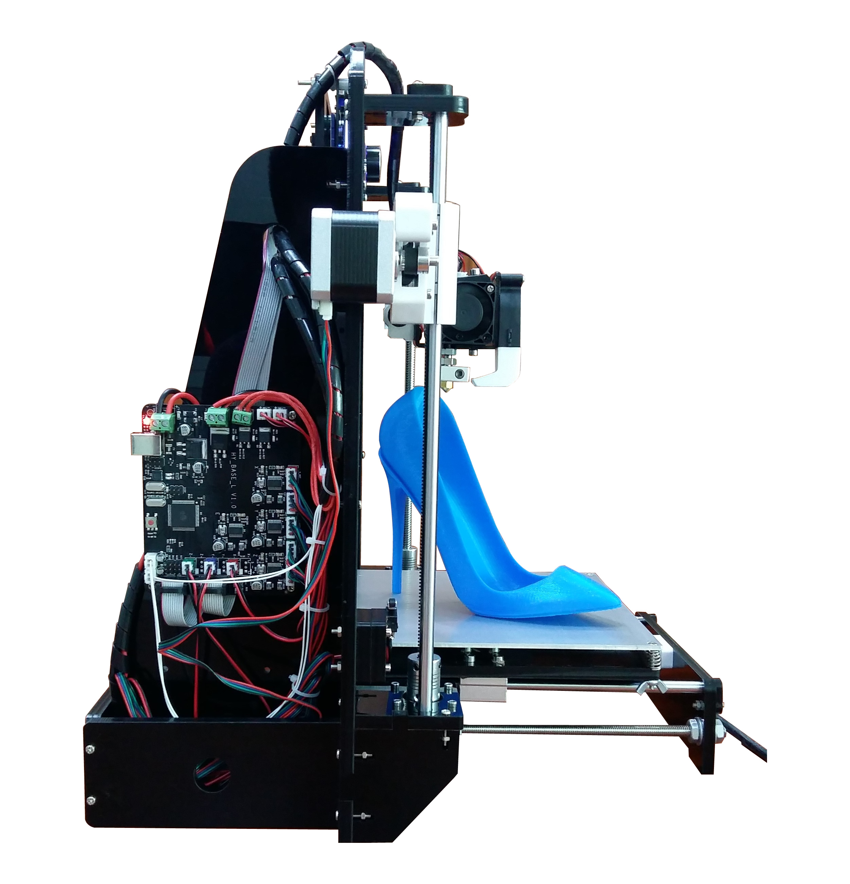
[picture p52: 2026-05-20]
Installation Instruction/Video/finish picture/D.jpg

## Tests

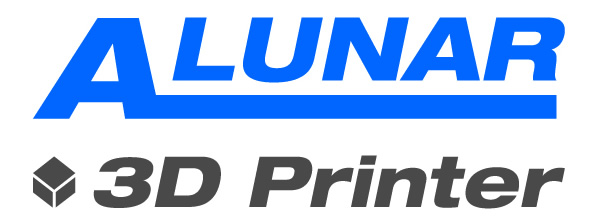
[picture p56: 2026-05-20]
TestFile/TestMode/htmimg/Alunar.jpg

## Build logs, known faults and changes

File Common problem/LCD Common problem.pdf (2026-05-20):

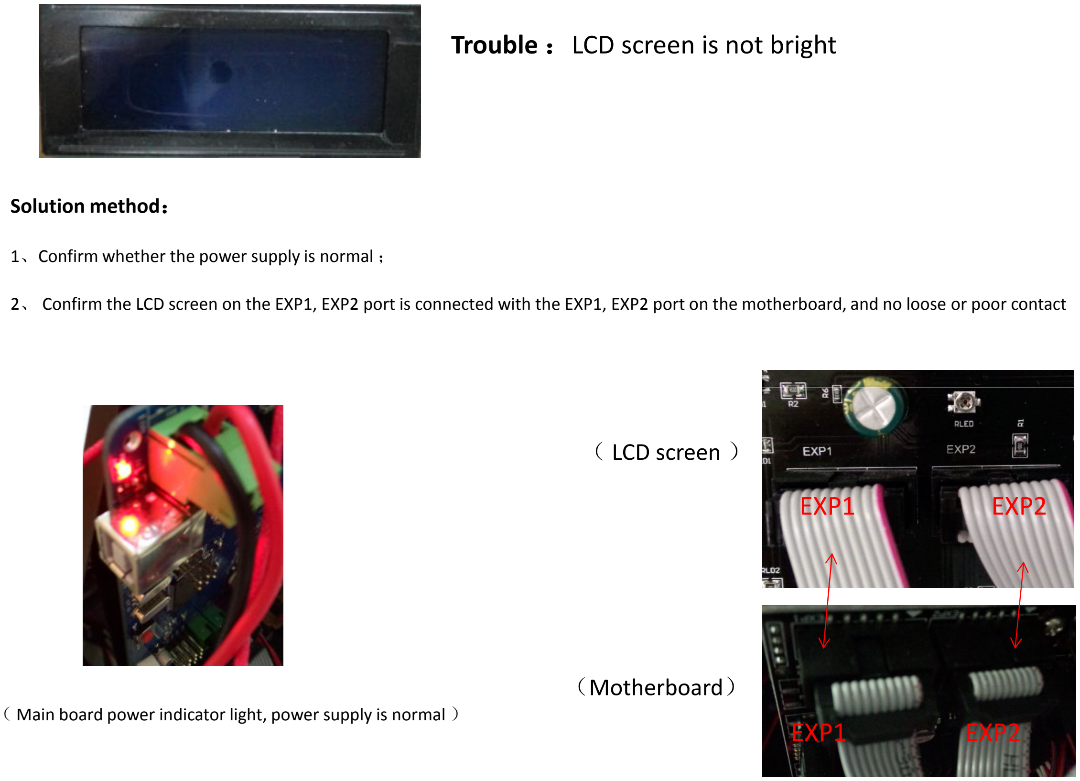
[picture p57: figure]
Solution method：; Trouble ：LCD screen is not bright; （ LCD screen ）; （Motherboard）; EXP1; EXP2

1、Confirm whether the power supply is normal ；

2、 Confirm the LCD screen on the EXP1, EXP2 port is connected with the EXP1, EXP2 port on the motherboard, and no loose or poor contact

（ Main board power indicator light, power supply is normal ）

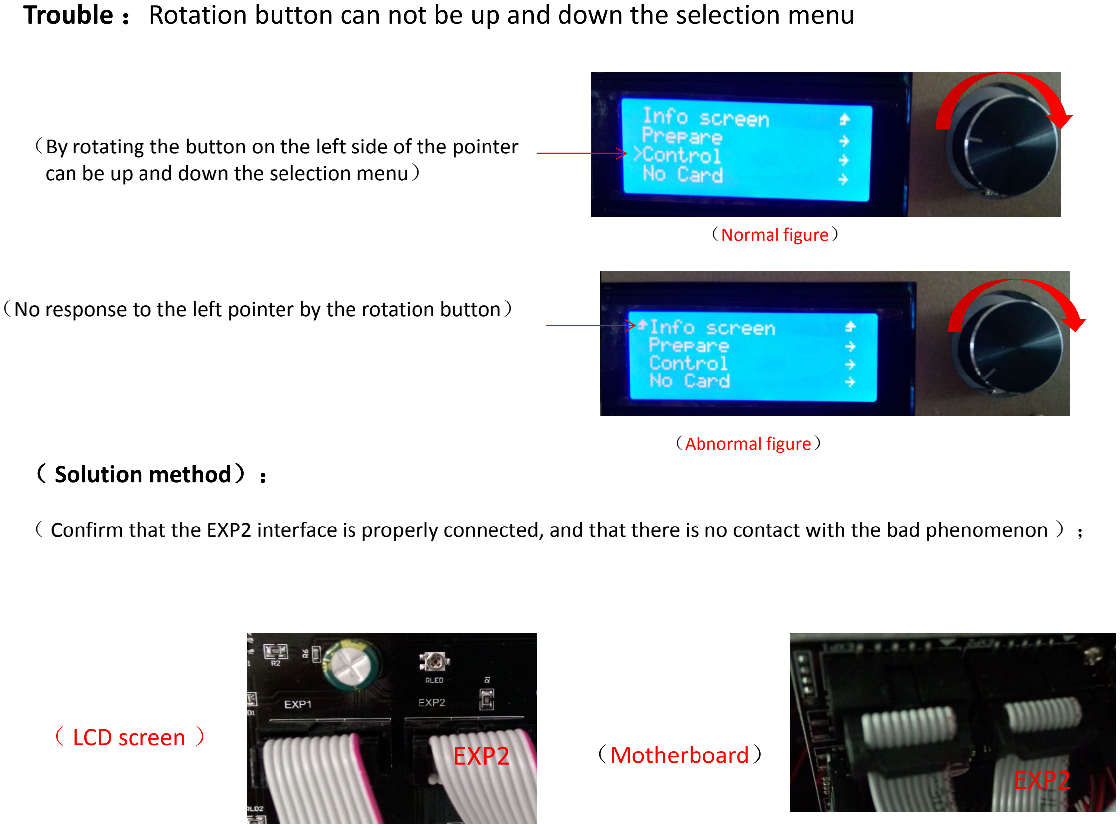
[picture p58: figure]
（Normal figure）; can be up and down the selection menu）; （ Solution method）：; （ LCD screen ）; EXP2; （Motherboard）; （Abnormal figure）

## Trouble ：Rotation button can not be up and down the selection menu

（By rotating the button on the left side of the pointer

（No response to the left pointer by the rotation button）

（ Confirm that the EXP2 interface is properly connected, and that there is no contact with the bad phenomenon ）；

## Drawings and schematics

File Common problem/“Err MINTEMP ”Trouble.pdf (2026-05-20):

## “Err: MINTEMP ” （Alarm processing method）

TB

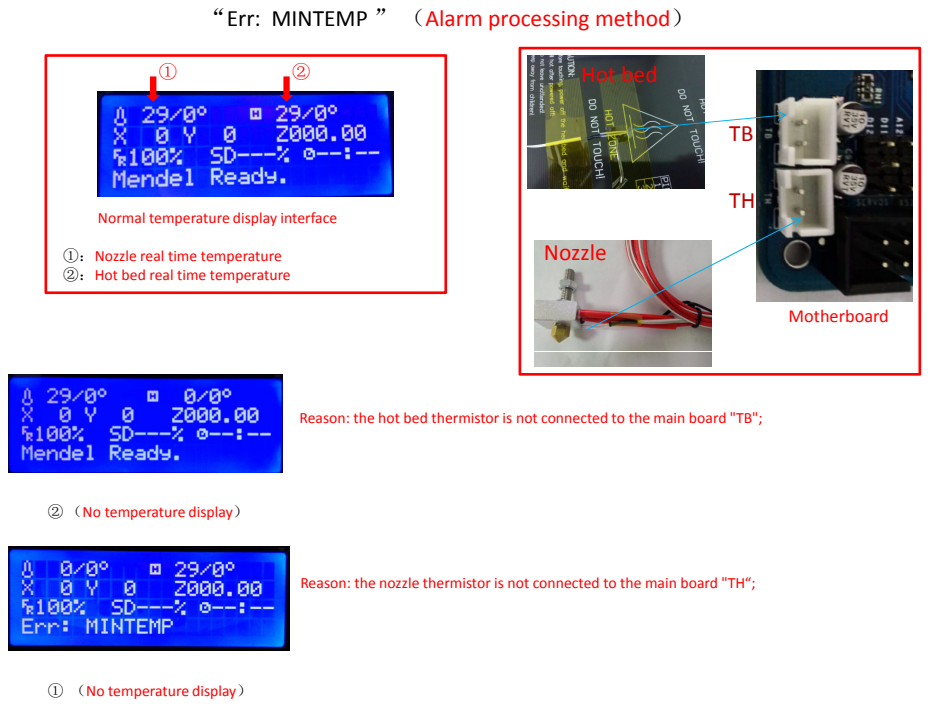
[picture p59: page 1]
Hot bed; Nozzle; Motherboard

Normal temperature display interface

①：Nozzle real time temperature
②：Hot bed real time temperature

Reason: the hot bed thermistor is not connected to the main board "TB";

② （No temperature display）

Reason: the nozzle thermistor is not connected to the main board "TH“;

① （No temperature display）

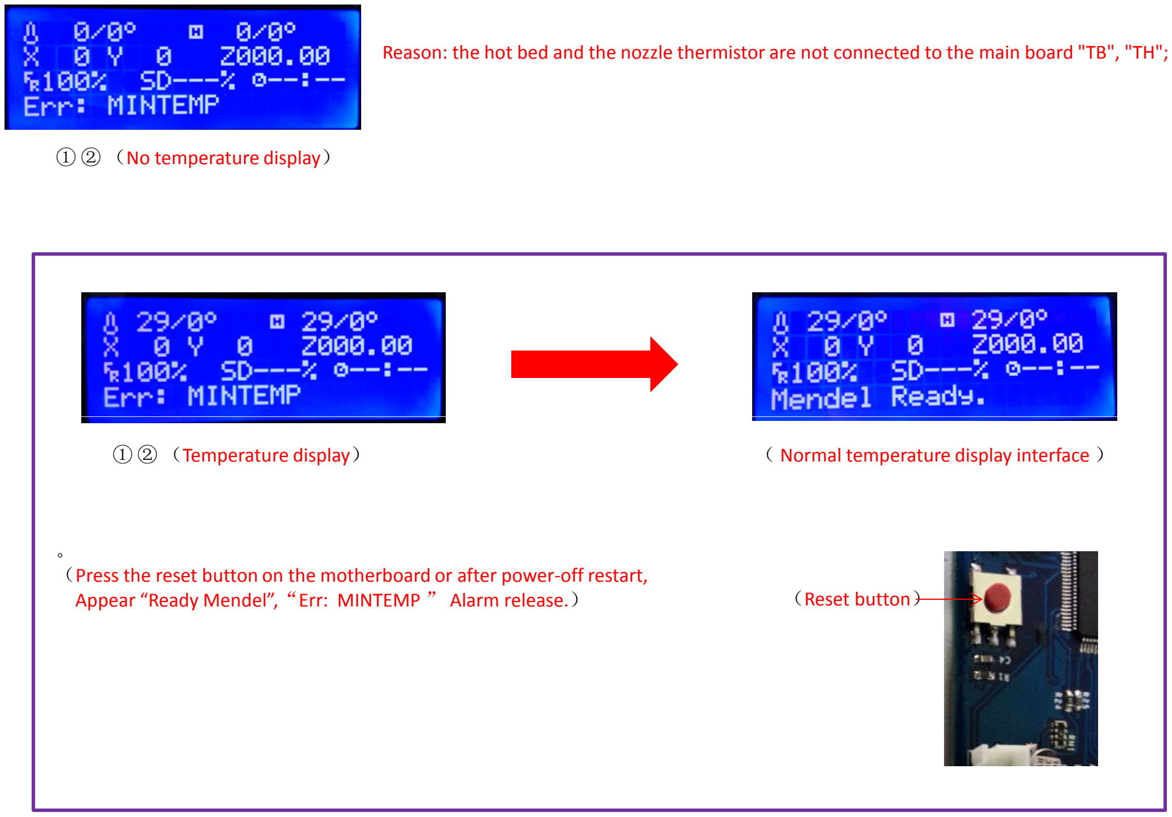
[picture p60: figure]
① ② （No temperature display）; Appear “Ready Mendel”,; “Err: MINTEMP; ” Alarm release.）; （Reset button）

Reason: the hot bed and the nozzle thermistor are not connected to the main board "TB", "TH";

（Press the reset button on the motherboard or after power-off restart,

① ② （Temperature display） | （ Normal temperature display interface ）

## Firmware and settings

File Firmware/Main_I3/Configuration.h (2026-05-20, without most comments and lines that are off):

#define CONFIGURATION_H
#define STRING_VERSION_CONFIG_H __DATE__ " " __TIME__ // build date and time
#define STRING_CONFIG_H_AUTHOR "(none, default config)" //Who made the changes.
#define SERIAL_PORT 0
#define BAUDRATE 250000
#define MOTHERBOARD 33
#define POWER_SUPPLY 1
#define TEMP_SENSOR_0 1
#define TEMP_SENSOR_1 0
#define TEMP_SENSOR_2 0
#define TEMP_SENSOR_BED 1
#define TEMP_RESIDENCY_TIME 10	// (seconds)
#define TEMP_HYSTERESIS 3       // (degC) range of +/- temperatures considered "close" to the target one
#define TEMP_WINDOW     1       // (degC) Window around target to start the recidency timer x degC early.
#define HEATER_0_MINTEMP 5
#define HEATER_1_MINTEMP 5
#define HEATER_2_MINTEMP 5
#define BED_MINTEMP 5
#define HEATER_0_MAXTEMP 275
#define HEATER_1_MAXTEMP 275
#define HEATER_2_MAXTEMP 275
#define BED_MAXTEMP 125
#define PIDTEMP
#define PID_MAX 256 // limits current to nozzle; 256=full current
  #define PID_FUNCTIONAL_RANGE 10 // If the temperature difference between the target temperature and the actual temperature
  #define PID_INTEGRAL_DRIVE_MAX 255  //limit for the integral term
  #define K1 0.95 //smoothing factor withing the PID
  #define PID_dT ((16.0 * 8.0)/(F_CPU / 64.0 / 256.0)) //sampling period of the temperature routine
    #define  DEFAULT_Kp 213.2
    #define  DEFAULT_Ki 1.54
    #define  DEFAULT_Kd 765
#define MAX_BED_POWER 256 // limits duty cycle to bed; 256=full current
#define EXTRUDE_MINTEMP 170
#define EXTRUDE_MAXLENGTH (X_MAX_LENGTH+Y_MAX_LENGTH) //prevent extrusion of very large distances.
#define ENDSTOPPULLUPS // Comment this out (using // at the start of the line) to disable the endstop pullup resistors
  #define ENDSTOPPULLUP_XMAX
  #define ENDSTOPPULLUP_YMAX
  #define ENDSTOPPULLUP_ZMAX
  #define ENDSTOPPULLUP_XMIN
  #define ENDSTOPPULLUP_YMIN
  #define ENDSTOPPULLUP_ZMIN
const bool X_ENDSTOPS_INVERTING = true; // set to true to invert the logic of the endstops.
const bool Y_ENDSTOPS_INVERTING = true; // set to true to invert the logic of the endstops.
const bool Z_ENDSTOPS_INVERTING = true; // set to true to invert the logic of the endstops.
#define X_ENABLE_ON 0
#define Y_ENABLE_ON 0
#define Z_ENABLE_ON 0
#define E_ENABLE_ON 0 // For all extruders
#define DISABLE_X false
#define DISABLE_Y false
#define DISABLE_Z false
#define DISABLE_E false // For all extruders
#define INVERT_X_DIR true   // for Mendel set to false, for Orca set to true
#define INVERT_Y_DIR true    // for Mendel set to true, for Orca set to false
#define INVERT_Z_DIR false     // for Mendel set to false, for Orca set to true
#define INVERT_E0_DIR true  // for direct drive extruder v9 set to true, for geared extruder set to false
#define INVERT_E1_DIR false    // for direct drive extruder v9 set to true, for geared extruder set to false
#define INVERT_E2_DIR false   // for direct drive extruder v9 set to true, for geared extruder set to false
#define X_HOME_DIR -1
#define Y_HOME_DIR -1
#define Z_HOME_DIR -1
#define min_software_endstops true //If true, axis won't move to coordinates less than HOME_POS.
#define max_software_endstops true  //If true, axis won't move to coordinates greater than the defined lengths below.
#define X_MAX_POS 205
#define X_MIN_POS 0
#define Y_MAX_POS 205
#define Y_MIN_POS 0
#define Z_MAX_POS 185
#define Z_MIN_POS 0
#define X_MAX_LENGTH (X_MAX_POS - X_MIN_POS)
#define Y_MAX_LENGTH (Y_MAX_POS - Y_MIN_POS)
#define Z_MAX_LENGTH (Z_MAX_POS - Z_MIN_POS)
#define MANUAL_X_HOME_POS 0
#define MANUAL_Y_HOME_POS 0
#define MANUAL_Z_HOME_POS 0
#define NUM_AXIS 4 // The axis order in all axis related arrays is X, Y, Z, E
#define HOMING_FEEDRATE {40*60, 40*60, 3*60, 0}  // set the homing speeds (mm/min)
#define DEFAULT_AXIS_STEPS_PER_UNIT   {100,100,400,92.6}      // default steps per unit for ultimaker
#define DEFAULT_MAX_FEEDRATE          {400, 400, 5, 25}    // (mm/sec)
#define DEFAULT_MAX_ACCELERATION      {9000,9000,100,10000}    // X, Y, Z, E maximum start speed for accelerated moves. E default values are good for skeinforge 40+, for older versions raise them a lot.
#define DEFAULT_ACCELERATION          3000    // X, Y, Z and E max acceleration in mm/s^2 for printing moves
#define DEFAULT_RETRACT_ACCELERATION  3000   // X, Y, Z and E max acceleration in mm/s^2 for r retracts
#define DEFAULT_XYJERK                20.0    // (mm/sec)
#define DEFAULT_ZJERK                 0.4     // (mm/sec)
#define DEFAULT_EJERK                 5.0    // (mm/sec)
#define SDSUPPORT // Enable SD Card Support in Hardware Console
#define REPRAP_DISCOUNT_SMART_CONTROLLER
 #define ULTIPANEL
 #define NEWPANEL
#define PLA_PREHEAT_HOTEND_TEMP 200
#define PLA_PREHEAT_HPB_TEMP 50
#define PLA_PREHEAT_FAN_SPEED 0		// Insert Value between 0 and 255
#define ABS_PREHEAT_HOTEND_TEMP 245
#define ABS_PREHEAT_HPB_TEMP 100
#define ABS_PREHEAT_FAN_SPEED 0		// Insert Value between 0 and 255
  #define SDSUPPORT
  #define ULTRA_LCD
  #define LCD_WIDTH 20
  #define LCD_HEIGHT 4
#include "Configuration_adv.h"
#include "thermistortables.h"

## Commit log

2026-05-20 Initial commit: ALUNAR M508 3D Printer instructions v2.0
    Includes firmware (Marlin-based), installation guides, videos,
    software references, packing list, and test files.
    [2016.stl, Configuration.h, Configuration_adv.h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]
2026-05-20 Add comprehensive README.md
    Covers assembly videos, firmware flashing, software setup,
    test files with previews, troubleshooting guides and packing list.
